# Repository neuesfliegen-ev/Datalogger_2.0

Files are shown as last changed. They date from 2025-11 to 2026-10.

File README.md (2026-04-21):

# 🛩️ Datalogger_2.0 

Datalogger for collecting, logging and transmitting RC flight data during the New Flying Competition
organised and held by the Neues Fliegen e.V.
Continuation of project Datalogger (first version)

---

## 🧩 Improvements

- Remove SIM card and use radio communication for telemetry
- Improve IMU sensor stability on flight
- Develop more efficient calibration process
- Develop a ground station capable of receiving and uploading live telemetry
- Implement FreeRTOS on ESP32

---

## 📦 Features

- Logs data to SD card in `.csv` format
- Captures:
  - 9-axis IMU data (acceleration, gyroscope, magnetometer)
  - Barometric pressure, altitude, and temperature
  - GPS coordinates, altitude, speed, and satellite count
- Streams telemetry to ground station through radio communication
- Ground station streams telemetry to web server
//to be refined

## 🧠 Core Components

| Component 	| Description |
|---|---|
| **ESP32** 		| Primary microcontroller |
| **WT-901B** 			  | 10-DOF IMU (acceleration, gyroscope, magnetometer + barometer)  |
| **GEP M10** 	| GEP-M10 GPS module utilizing the u-blox M10050 GPS chip |
| **Digital pitot sensor** | PixHawk PX4 digital airspeed sensor |
| **E22-900T30D LoRa module**	| Enables the transmission of live telemetry via radio communication to ground station|
| **SD Card Module** 	| Stores `.csv` data logs |
//more to be added

---

## 🔧 Circuit Diagram
//to be added

---

## 👨‍💻 Credits

- Developed by the **Neues Fliegen e.V.** team
- Based on libraries by Arduino...

---

## 📷 License

- This project is shared publicly for educational and personal use only.
Commercial use or sale is not permitted without explicit permission
from Neues Fliegen e.V.
- see LICENSE file

---

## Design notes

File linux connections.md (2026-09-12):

# LoRa Radio Module Configuration & Message Transmission

## Radio Module Configuration
Problem with radio link? It's usually the hardware settings (module configuration).

Configuration settings to be set:
| AT command | Meaning |
|---|---|
| AT+UART=7,0 | 115200 baud rate, 8N1 |
| AT+RATE=5 | 19.2 kbps |
| AT+CHANNEL=1 | using channel 1 |
| AT+ADDR=1 | set different number for each module |

### 1. Wiring

Wire the USB-TTL converter to the LoRa module.

| Pin | Level |
|---|---|
| M1 | HIGH |
| M0 | GND |

### 2. Configure the Serial Port

In the **left terminal window**, connect to the correct `/dev/ttyUSB0` port:

```bash
sudo stty -F /dev/ttyUSB0 115200 cs8 -cstopb -parenb raw -echo
```

If the module hasn't been set to 115200 baud rate yet, then use the default 9600.

!!!!!You need the raw or else u get an error

### 3. Listen to the Port

In the **left terminal window**:

```bash
cat /dev/ttyUSB0
```

Keep this running to listen for responses from the module.

### 4. Send an AT Command

In the **right terminal window**:

```bash
sudo echo "AT+HELP=?" > /dev/ttyUSB0
```

### Common Errors

#### Port Busy

Usually caused by another program or terminal session already using `/dev/ttyUSB0`.

Close the other session or application using the port.

#### Permission Denied

If you get a permission error when accessing the serial port, add your user to the `dialout` group:

```bash
sudo usermod -aG dialout $USER
```

Log out and back in for the group change to take effect.

---

# Sending Messages

For normal transmission mode, set both pins to GND:

| Pin | Level |
|---|---|
| M1 | GND |
| M0 | GND |

### 1. Keep the Listener Running

Keep the following command running in the **left terminal window**:

```bash
cat /dev/ttyUSB0
```

### 2. Send Binary Data

In the **right terminal window**:

```bash
printf '\x01\x02\x03\x04' > /dev/ttyUSB0
```

### 3. Send Text

Send plain text:

```bash
printf 'text' > /dev/ttyUSB0
```

Or send text followed by a newline:

```bash
printf 'text\n' > /dev/ttyUSB0
```

The receiving LoRa module should output the transmitted data through its serial interface.



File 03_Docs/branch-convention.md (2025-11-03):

# 🌳 Branch Naming & Workflow Convention

To keep our collaboration organized and avoid conflicts, please follow these guidelines when creating and managing branches.

> See also: [📜 GitHub Best Practices](\docs\github-best-practices.md)

---

### 🌿 1. Creating Branches
- **Create a new branch** for every new feature, bug fix, or major change.  
- Ideally, **one person works on one branch** at a time.  
  This keeps history clean and prevents conflicting edits.

---

### 🏷️ 2. Naming Conventions
- Use **descriptive, lowercase, hyphen-separated names** that reflect the purpose of the branch.  
  Examples:
  - `feature/implement-oled`
  - `bugfix/fix-timing-loop`
  - `experiment/new-gps-module`

This makes it easy for everyone to understand what each branch is for at a glance.

---

### 🔄 3. Keeping Your Branch Up to Date
- If `main` gets updated while you’re working, **rebase your branch** onto the latest `main`.  
  This ensures your work includes the newest changes and reduces merge conflicts later.  
  *(Command line: `git fetch origin && git rebase origin/main` or let GitHub Desktop handle it 🤷🏼)*.

---

### 🚀 4. Opening Pull Requests
- When your code is ready and tested, **push your branch** to GitHub and open a **Pull Request (PR)**.  
- Request at least one teammate to review before merging into `main`.

---

### 🧹 5. Cleaning Up
- After your PR is merged, delete your branch locally. Your branch on GitHub will be deleted automatically.
- This keeps the repository tidy and prevents confusion.

---

### 🤓☝🏼 6. Exceptions
- If you’re working on something that **no one else will touch** (e.g., a personal test file or documentation),  
  you don’t need to strictly follow this branching convention.  
- Just make sure your work doesn’t interfere with shared code.

---

### ⚠️ Important Notes

- Never rebase or force-push shared branches that others might be using.
Only rebase your own feature branches.

- When in doubt, **ask before merging** — better a small delay than broken code!

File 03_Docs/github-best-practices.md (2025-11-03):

# 📜 GitHub Best Practices

A few simple habits to keep our workflow smooth, organized, and conflict-free.

> See also: [🌿 Branch Naming & Workflow Convention](\docs\branch-convention.md)

---

### 💬 1. Commit Messages
- Keep commit messages **short, clear, and descriptive**.  
  *(Example: “Fix timing issue in motor control loop”)*  
- Write messages that explain **what** changed and, if relevant, **why**.

---

### 💾 2. Committing
- **Commit often** — after completing a small, logical unit of work.  
- It’s okay to commit code that’s incomplete or not yet working, as long as it’s **not pushed**.  
  Think of commits as personal save points.

---

### 🔄 3. Staying Updated
- **Fetch (or pull) from `main` regularly** to stay in sync with the latest changes.  
  This reduces merge conflicts and keeps your branch current.
  
---
  
### 🚀 4. Pushing
- **Push only when your code builds and runs reliably.**  
  That way, the shared repository always reflects working code.  
- After rebasing or resolving conflicts, remember to push with  
  `--force-with-lease` (or let GitHub Desktop handle it 🤷🏼).

---

### 🌿 5. Branching
- **Create a new branch for every feature, fix, or experiment.**  
  *(Example: `feature/add-sensor`, `bugfix/fix-display`)*  
- Keep branches short-lived — merge them once the feature is complete and tested.

---

### 📝 Summary
- Commit early, push late.  
- Fetch often, branch freely, and ***keep `main` clean***. (please)

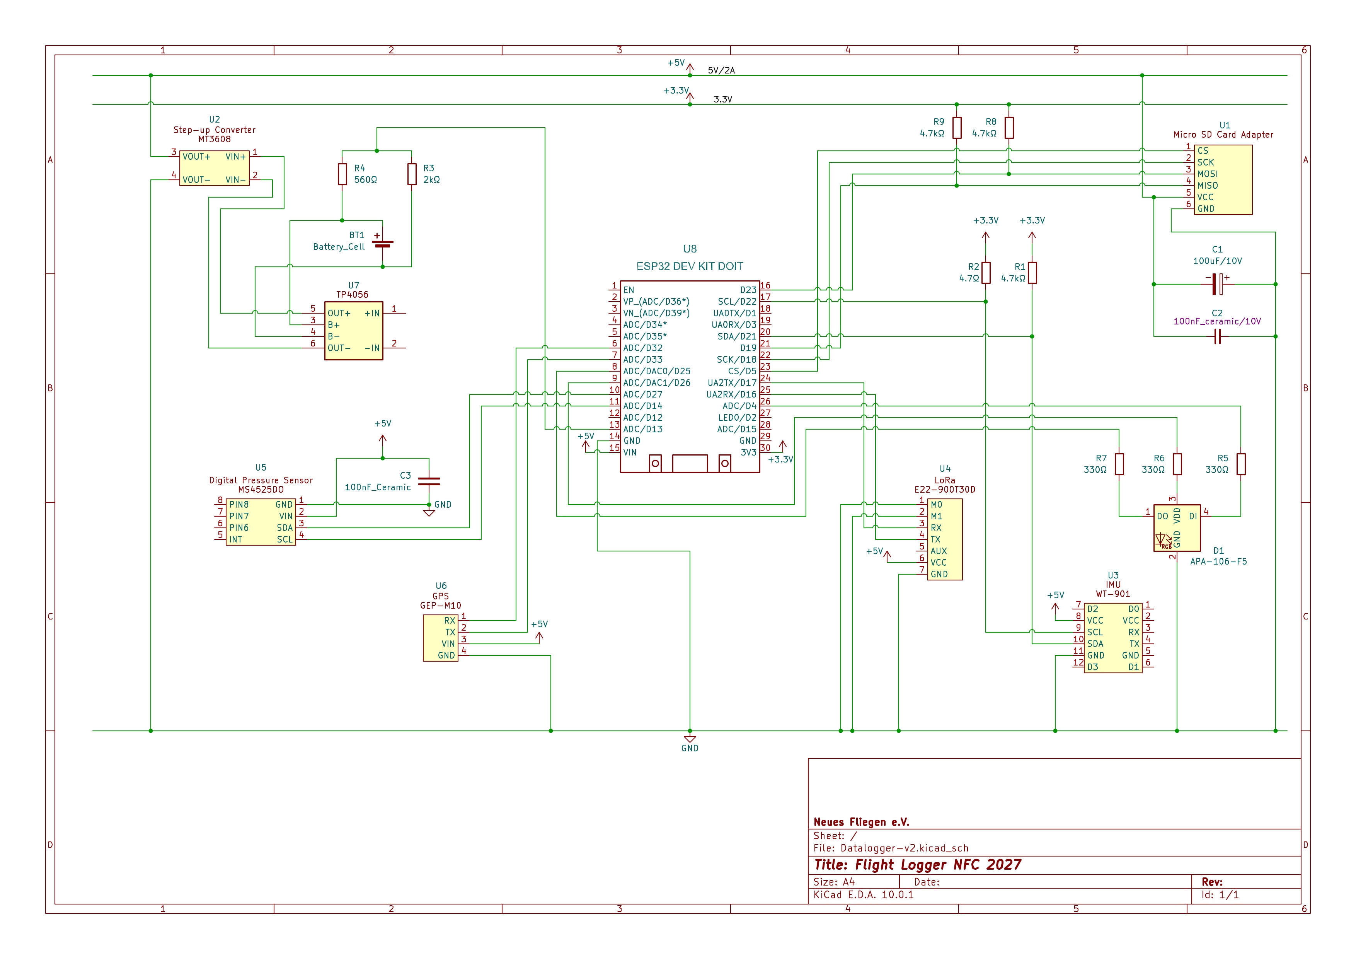
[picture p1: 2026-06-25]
02_PCB/Schematic Flight Logger NFC27 v1.0.jpg

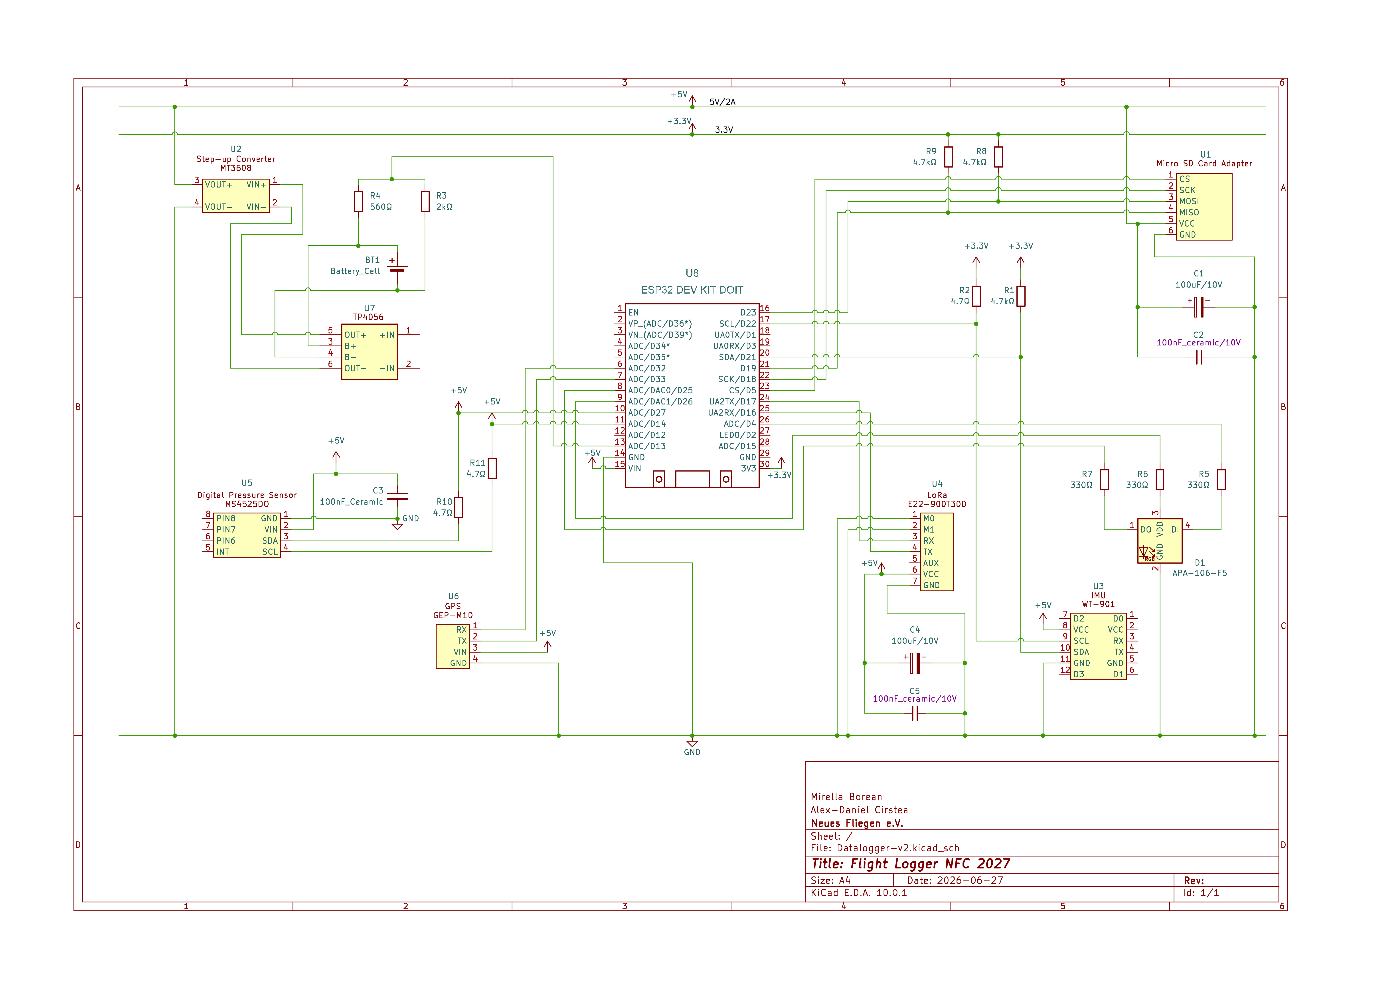
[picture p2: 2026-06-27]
02_PCB/Schematic Flight Logger NFC27 27-06 v1.1.png

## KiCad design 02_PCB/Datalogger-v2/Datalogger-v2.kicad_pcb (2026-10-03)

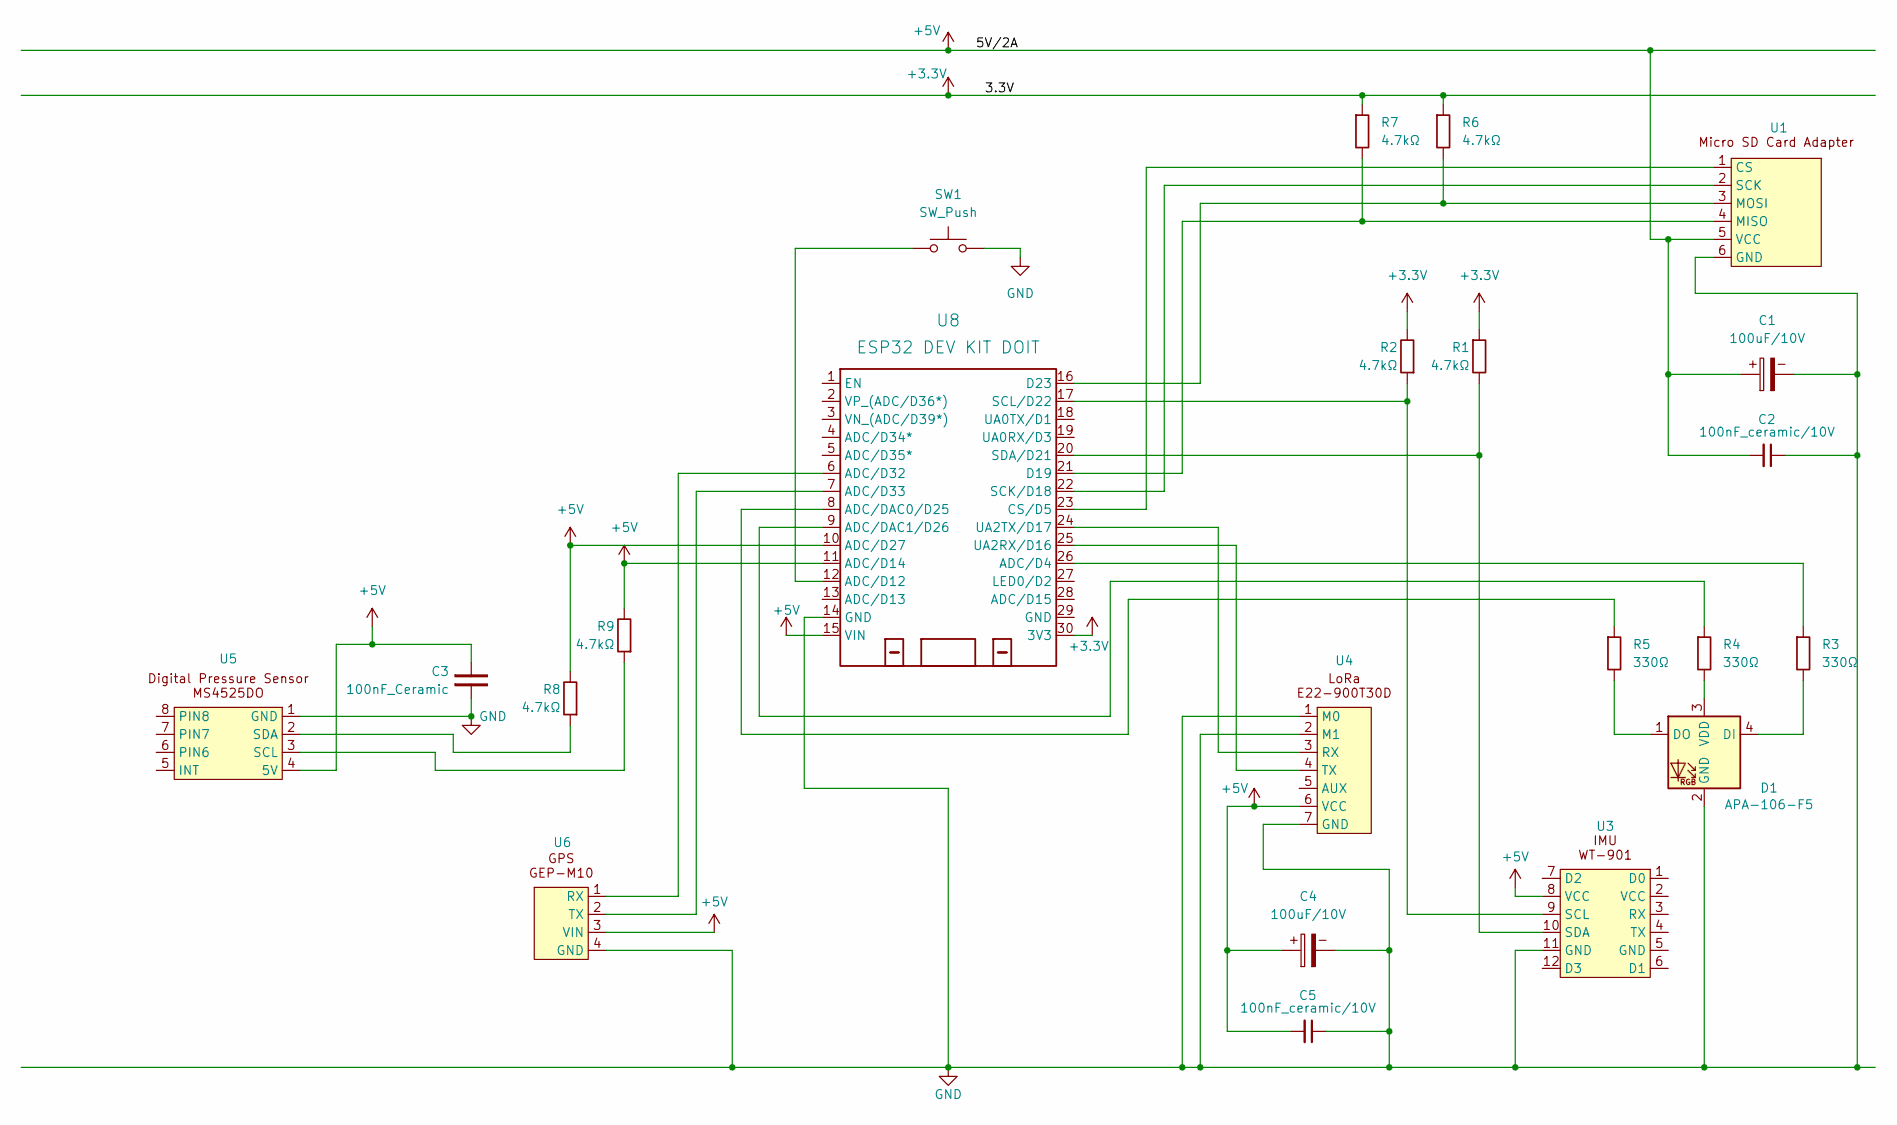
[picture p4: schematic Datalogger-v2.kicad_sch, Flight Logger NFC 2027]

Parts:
C1, C4: 100uF/10V; CP_Radial_D5.0mm_P2.50mm
C2, C5: 0.1uF_0603_16V; C_0805_2012Metric_Pad1.18x1.45mm_HandSolder; Part Number 0603YC104KAT2A; JLCPCB ID C14663
C3: 100nF_Ceramic; C_0805_2012Metric_Pad1.18x1.45mm_HandSolder
D1: APA-106-F5; LED_D5.0mm-4_RGB
R1, R2, R6, R7, R8, R9: 4.7kΩ; R_Axial_DIN0207_L6.3mm_D2.5mm_P10.16mm_Horizontal
R3, R4, R5: 330Ω; R_Axial_DIN0207_L6.3mm_D2.5mm_P10.16mm_Horizontal
SW1: SW_Push; SW_PUSH_6mm
U1: Micro SD Card Adapter; Micro_SD_Adapter
U3: WT901B
U4: E22-900T30D
U5: MS4525DO
U6: GPS GEP-M10
U8: ESP32 DEV KIT DOIT; DOIT-ESP32-DEVKIT-V1

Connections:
+3.3V: R1.1, R2.2, R6.1, R7.1, U8.30 (3V3)
+5V: C1.1, C2.2, C3.1, C4.1, C5.2, R8.2, R9.2, U1.5 (VCC), U3.8 (VCC), U4.6 (VCC), U5.4 (5V), U6.3 (VIN), U8.10 (ADC/D27), U8.11 (ADC/D14), U8.15 (VIN)
GND: C1.2, C2.1, C3.2, C4.2, C5.1, D1.2 (GND), SW1.2, U1.6 (GND), U3.11 (GND), U4.1 (M0), U4.2 (M1), U4.7 (GND), U5.1 (GND), U6.4 (GND), U8.14 (GND)
unnamed: D1.4 (DI), R3.2
unnamed: D1.1 (DO), R5.2
unnamed: D1.3 (VDD), R4.2
unnamed: U1.1 (CS), U8.23 (CS/D5)
unnamed: R7.2, U1.4 (MISO), U8.21 (D19)
unnamed: R6.2, U1.3 (MOSI), U8.16 (D23)
unnamed: U1.2 (SCK), U8.22 (SCK/D18)
unnamed: R2.1, U3.9 (SCL), U8.17 (SCL/D22)
unnamed: R1.2, U3.10 (SDA), U8.20 (SDA/D21)
unnamed: U4.3 (RX), U8.24 (UA2TX/D17)
unnamed: U4.4 (TX), U8.25 (UA2RX/D16)
unnamed: R9.1, U5.3 (SCL)
unnamed: R8.1, U5.2 (SDA)
unnamed: U6.1 (RX), U8.6 (ADC/D32)
unnamed: U6.2 (TX), U8.7 (ADC/D33)
unnamed: R3.1, U8.26 (ADC/D4)
unnamed: SW1.1, U8.12 (ADC/D12)
unnamed: R5.1, U8.8 (ADC/DAC0/D25)
unnamed: R4.1, U8.9 (ADC/DAC1/D26)

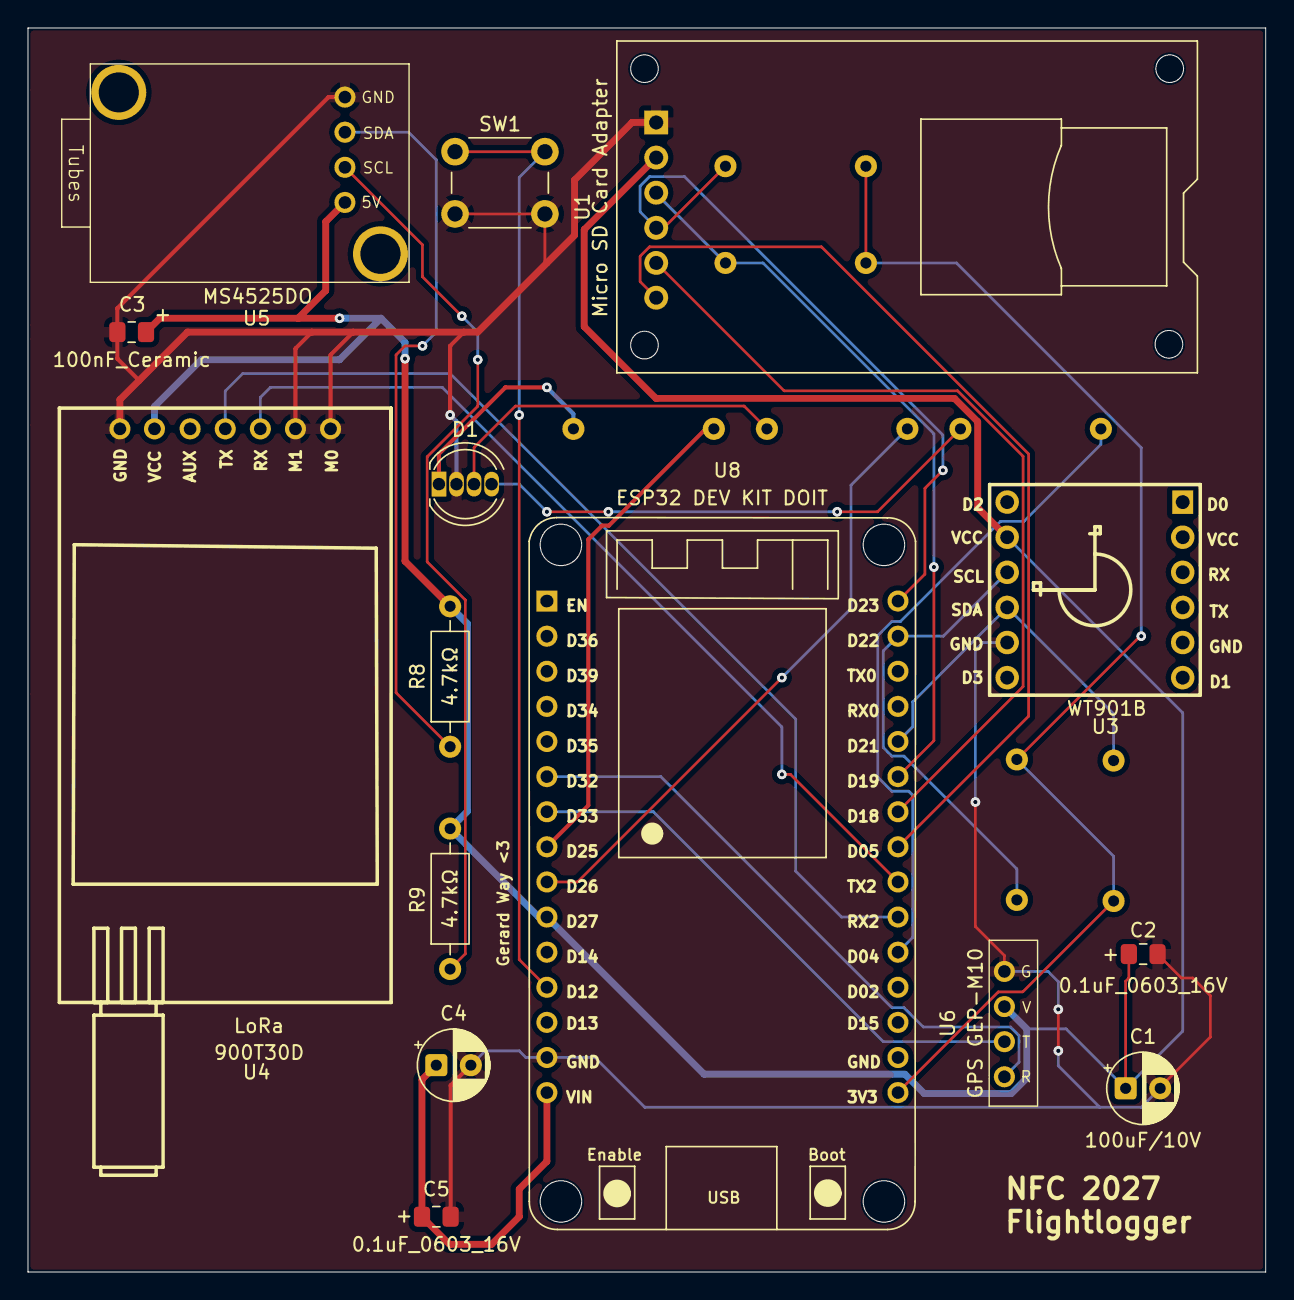
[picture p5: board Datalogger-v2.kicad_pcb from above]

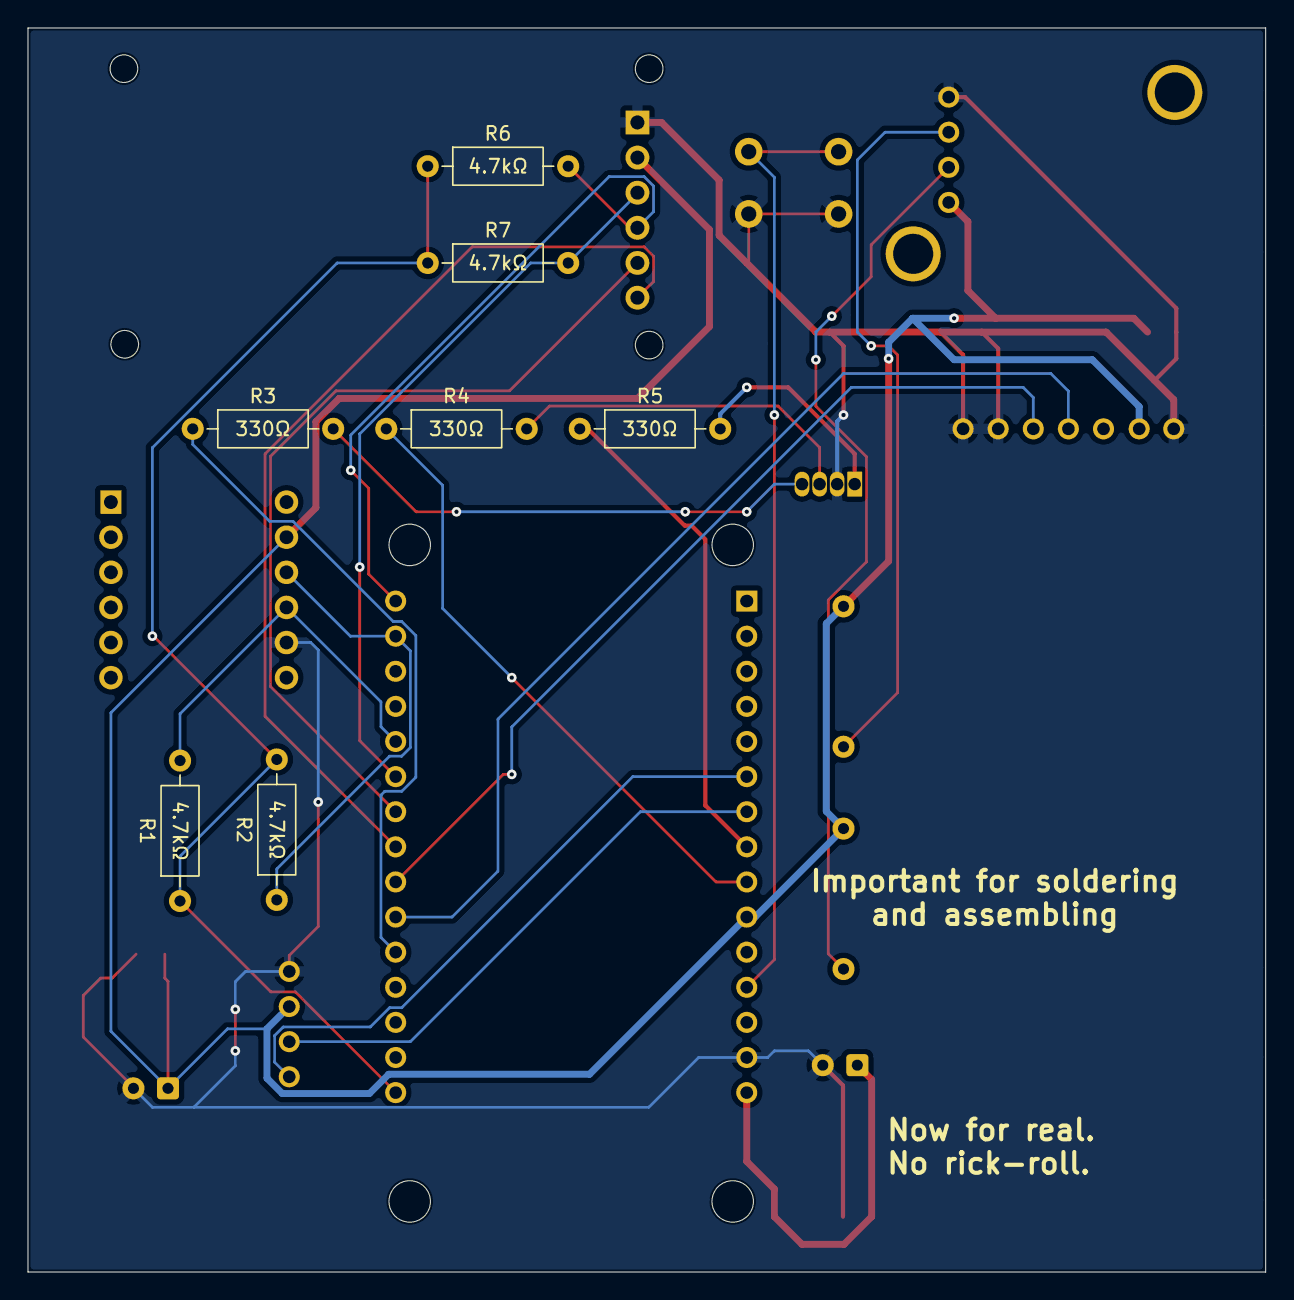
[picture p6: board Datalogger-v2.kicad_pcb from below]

Board: 2 copper layers, 89.5 x 90.0 mm, 22 parts (7 on the bottom side), 22 nets.

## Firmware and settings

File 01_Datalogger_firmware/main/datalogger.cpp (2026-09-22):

/*DO NOT RUN BUS SETUP FUNCTIONS WITHOUT HARDWARE CONNECTION: comment out in serial_buses_setup()*/

/* C Libraries */
#include <stdio.h>
#include <string.h>

/* ESP-IDF */
#include "freertos/FreeRTOS.h"
#include "freertos/task.h"
#include "esp_timer.h"
#include "esp_log.h"
#include "driver/gpio.h"
#include "driver/i2c_master.h"
#include "driver/uart.h"
#include "driver/spi_common.h"
#include "driver/sdspi_host.h"
#include "sdmmc_cmd.h"

/* Local */
#include "pins.h"
#include "setup.h"
#include "hal/radio.h"
#include "hal/imu.h"
#include "hal/gps.h"
#include "hal/airspeed.h"
#include "modules/telemetry.h"
#include "modules/commandHandler.h"
#include "hal/sd_card.h"

/* Settings */
bool DEBUG = true;
bool TELEMETRY_ENABLED = false;
bool LOGGING_ENABLED = true;

QueueHandle_t datasetQueue;
QueueHandle_t radioQueue;
int command, option; 

//Module objects
SDCard sd;
Telemetry telemetry;
CJY901 IMU;
AirspeedClass airspeed;
GPSClass GPS;
RadioClass Radio(RADIO_M0_PIN, RADIO_M1_PIN);
CommandHandler commandHandler(Radio, IMU, airspeed, GPS, sd, telemetry, LOGGING_ENABLED, TELEMETRY_ENABLED);

static uint32_t last_gps_update = 0;
static uint32_t last_imu_update = 0;
static uint32_t last_airspeed_update = 0;
static uint32_t last_radio_tx = 0;

void generateFileName(char *buffer, size_t buffer_size){
    int64_t ms = esp_timer_get_time() / 1000;

    snprintf(
        buffer,
        buffer_size,
        "/sdcard/21062026_%lld_test_file.bin",
        ms
    );
}

void update_all_sensor_data(){
	uint32_t now = esp_timer_get_time() / 1000;
	/* **update all the data structs**/
	/*0.7 ms*/
	if (now - last_airspeed_update >= AIRSPEED_UPDATE_PERIOD) {
	int64_t t0 = esp_timer_get_time();
	esp_err_t err = airspeed.read();
		//int64_t t1 = esp_timer_get_time();
		//printf("airspeed read time = %.2f ms\n", (t1 - t0) / 1000.0);    	
	last_airspeed_update = now;
	}	

	/*$=ms max.*/
	if (now - last_gps_update >= GPS_UPDATE_PERIOD) {
		int64_t t2 = esp_timer_get_time();	
    	GPS.update();
    	int64_t t3 = esp_timer_get_time();
    	//printf("gps read time = %.2f ms\n", (t3 - t2) / 1000.0);    	
    	last_gps_update = now;
	}	
	/*6ms?*/
	int64_t t4 = esp_timer_get_time();
	IMU.updateAll(); 
		int64_t t5 = esp_timer_get_time();
    	//printf("IMU read time = %.2f ms\n", (t5 - t4) / 1000.0);    		
	last_imu_update = now;
	/*1ms?*/
	telemetry.update_telemetry(now, IMU, GPS, airspeed); 

	if(DEBUG) ESP_LOGI("TELEMETRY", "updated telemetry\n");
}

//Read sensors, read radio commands
void polling_task(void *pvParameters) {
	RadioMessage msg;
    
    for(;;) {
    	
    	update_all_sensor_data(); 

        // Queue data for SD
        if (LOGGING_ENABLED) {
            if (xQueueSend(datasetQueue, &telemetry.dataset, 0) != pdTRUE) {
                ESP_LOGW("SD QUEUE", "datasetQueue full, sample dropped");
            }
        }    
		
		if (Radio.readCommand(command, option)){
			commandHandler.executeCommand(command, option);
		}

		uint32_t now = esp_timer_get_time() / 1000;
		if(TELEMETRY_ENABLED && (now - last_radio_tx > TELEMETRY_PERIOD)){
			int64_t t0 = esp_timer_get_time();
			Radio.sendDataset(&telemetry);
			int64_t t1 = esp_timer_get_time();

			printf("sendDataset took %.2f ms\n", (t1 - t0) / 1000.0);
			last_radio_tx = now;
		}

        // IMPORTANT: give other tasks CPU time
        vTaskDelay(pdMS_TO_TICKS(10));

    }
}

//Radio TX Parsing
void radio_tx_task(void *arg) {
    RadioMessage msg;

    for (;;) {
    	if(TELEMETRY_ENABLED){
    		// Blocking is fine here because this task ONLY handles TX
    		if (xQueueReceive(radioQueue, &msg, portMAX_DELAY) == pdTRUE) {

            int written = uart_write_bytes(RADIO_UART_NUM, msg.text, msg.len);

            if(DEBUG)ESP_LOGI("RADIO TX","sent %d/%d bytes",written,msg.len);
        	}
    	}
    }
}

//Log to SD
void logging_task(void* arg) {
	if(LOGGING_ENABLED){
		SDataset writeBuffer[32];
		size_t count = 0;
		uint32_t flush_counter = 0;

		for (;;) {
		    SDataset sample;
		    
		    if (xQueueReceive(datasetQueue, &sample, portMAX_DELAY) == pdTRUE) {
		        writeBuffer[count++] = sample;
		        if (count >= 32) {
		            esp_err_t err = sd.writeDatasets(writeBuffer, count);
		            if (err != ESP_OK) {
	    				ESP_LOGE("SD", "write failed: %s", esp_err_to_name(err));
					}else{
						ESP_LOGW("SD QUEUE", "wrote to sd card");					
					}
		            count = 0;

		            flush_counter++;

		            if (flush_counter >= 4) {
		                esp_err_t errFlush = sd.flush();
		                if(errFlush != ESP_OK) ESP_LOGE("SD QUEUE", "flush failed");
						
						if (err != ESP_OK) {
						    ESP_LOGE("SD QUEUE", "SD end failed: %s", esp_err_to_name(err));
						}	                
						flush_counter = 0;
						int time = esp_timer_get_time();
						if(time >= 300000000) sd.end();
		            
		            }
		            if(DEBUG) ESP_LOGI("SD CARD", "flushed file");	        
		        }
		    }
		}		
	}

}

extern "C" void app_main(){
	//esp_bt_controller_mem_release(ESP_BT_MODE_BTDM);
	sd.begin();
	serial_buses_setup();

	/*Create binary file (test phase) ---------
	char filename[64];
	generateFileName(filename, sizeof(filename));
	sd.openLogFile(filename);
	-----------------------------------------*/

	radioQueue = xQueueCreate(10, sizeof(RadioMessage));
	Radio.setQueue(radioQueue);

	datasetQueue = xQueueCreate(32, sizeof(SDataset));

	   // Sensors + command RX
    xTaskCreatePinnedToCore(
        polling_task,
        "polling_task",
        4096,
        NULL,
        5,
        NULL,
        0
    );

    // Radio TX
    xTaskCreatePinnedToCore(
        radio_tx_task,
        "radio_tx_task",
        2048,
        NULL,
        4,
        NULL,
        0
    );

	xTaskCreatePinnedToCore(logging_task, "logging_task", 6144, NULL, 6, NULL, 1);
	//xTaskCreatePinnedToCore(gps_task, "gps_task", 1024, NULL, 7, NULL, 0);

	//Verify radio link by sending message over UART
	Radio.sendMessage("hello hello hello, datalogger radio link is up\n");

}

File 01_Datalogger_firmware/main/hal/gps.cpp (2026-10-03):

#include <cstring>
#include <cstdlib>
#include "freertos/FreeRTOS.h"

#include "driver/uart.h"
#include "hal/gps.h"


void GPSClass::startUART(uart_port_t p){
	uart_num = p;
}

void GPSClass::update(){
    uint8_t c;

    while (uart_read_bytes(uart_num, &c, 1, 5 / portTICK_PERIOD_MS) > 0) {
        if (c == '\n') {
            line_[index_] = '\0';

            if (index_ > 6 && line_[0] == '$') {
                parseLine(line_);
            }

            index_ = 0;
        } else if (c != '\r') {
            if (index_ < sizeof(line_) - 1) {
                line_[index_++] = static_cast<char>(c);
            } else {
                index_ = 0;
            }
        }
    }
}

void GPSClass::parseLine(char* line) {
    if (std::strstr(line, "GGA")) {
        parseGGA(line);
    } else if (std::strstr(line, "RMC")) {
        parseRMC(line);
    } else if (std::strstr(line, "VTG")) {
        parseVTG(line);
    }
}

void GPSClass::parseGGA(char* line)
{
    char* f[16] = {};
    splitNMEA(line, f, 16);

    parseTime(f[1], dateTime_.time);

    if (f[2] && f[3])
        gps_.latitude = parseCoord(f[2], f[3][0]);

    if (f[4] && f[5])
        gps_.longitude = parseCoord(f[4], f[5][0]);

    if (f[7])
        gps_.satellites = static_cast<uint8_t>(std::atoi(f[7]));

    if (f[9])
        gps_.altitude = parseAltitude(f[9]);
}

void GPSClass::parseRMC(char* line)
{
    char* f[16] = {};
    splitNMEA(line, f, 16);

    if (!f[2] || f[2][0] != 'A') return;

    parseTime(f[1], dateTime_.time);

    if (f[3] && f[4])
        gps_.latitude = parseCoord(f[3], f[4][0]);

    if (f[5] && f[6])
        gps_.longitude = parseCoord(f[5], f[6][0]);

    if (f[7])
        gps_.speed = parseSpeedKnots(f[7]);

    if (f[9])
        parseDate(f[9], dateTime_.date);
}

void GPSClass::parseVTG(char* line)
{
    char* f[16] = {};
    splitNMEA(line, f, 16);

    if (f[7])
        gps_.speed = static_cast<uint16_t>(std::atof(f[7]) * 100.0);
}

int GPSClass::splitNMEA(char* line, char* fields[], int maxFields)
{
    int count = 0;

    char* star = std::strchr(line, '*');
    if (star) *star = '\0';

    char* p = line;

    while (p && count < maxFields) {
        fields[count++] = p;

        p = std::strchr(p, ',');
        if (p) {
            *p = '\0';
            p++;
        }
    }

    return count;
}

int32_t GPSClass::parseCoord(const char* s, char hemi)
{
    if (!s || !*s) return 0;

    double raw = std::atof(s);
    int deg = static_cast<int>(raw / 100);
    double min = raw - deg * 100;
    double dec = deg + min / 60.0;

    if (hemi == 'S' || hemi == 'W') dec = -dec;

    return static_cast<int32_t>(dec * 10000000.0);
}

int32_t GPSClass::parseAltitude(const char* s)
{
    if (!s || !*s) return 0;
    return static_cast<int32_t>(std::atof(s) * 100.0);
}

uint16_t GPSClass::parseSpeedKnots(const char* s)
{
    if (!s || !*s) return 0;

    double knots = std::atof(s);
    double kmh = knots * 1.852;

    return static_cast<uint16_t>(kmh * 100.0);
}

void GPSClass::parseTime(const char* s, SGPSTime& time)
{
    if (!s || !*s) return;

    double val = std::atof(s);
    uint32_t whole = static_cast<uint32_t>(val);

    time.hour = whole / 10000;
    time.minute = (whole / 100) % 100;
    time.second = whole % 100;
    time.millisecond = static_cast<uint16_t>((val - whole) * 1000.0);
}

void GPSClass::parseDate(const char* s, SGPSDate& date)
{
    if (!s || !*s) return;

    uint32_t val = static_cast<uint32_t>(std::atoi(s));

    date.day = val / 10000;
    date.month = (val / 100) % 100;
    date.year = 2000 + (val % 100);
}

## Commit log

2025-10-29 Create aboutthisfolder.txt
    for arduino testing
2026-02-27 Manuals
    - IMU: WT901
    - Microcontroller: ESP32
    - Radio Module: E22-900T30D
2026-02-27 Manuals
    LiPo battery
2026-03-27 Implement Pitot sensor module
    - Implement Pitot class in Pitot.cpp and Pitot.h.
    - Add functions for differential pressure and airspeed calculation.
    - Initialize and handle raw I2C sensor readings with EMA filtering.
2026-04-20 Removed Arduino directory
    Unneeded
2026-04-20 Create README.md
    Everything for ground station
2026-04-21 working imu driver
2026-04-30 imu folder
2026-05-04 added com ports and bug fixes
    [radio.cpp]
2026-05-15 Create PCB folder
2026-05-15 Create PCB directory
2026-05-15 Add schematic and PCB files
    [Datalogger-v2.kicad_pcb, Datalogger-v2.kicad_sch]
2026-05-20 change files names to imu.h
2026-05-20 Change folder name and structures
    [Datalogger-v2.kicad_pcb, Datalogger-v2.kicad_sch]
2026-06-03 separated imu register file to prevent conflicts with global; bug fixes in gps and imu classes
    [datalogger.cpp, gps.cpp]
2026-06-09 added airspeed sensor classes and updated Telemetry
2026-06-10 Update PCB schematic
    [Datalogger-v2.kicad_pcb, Datalogger-v2.kicad_sch]
2026-06-10 Update schematic and PCB files
    - Add symbol and footprint library.
    [Datalogger-v2.kicad_pcb, Datalogger-v2.kicad_sch]
2026-06-10 Update PCB file
    - Fix design rules
    - Add tracks
    [Datalogger-v2.kicad_pcb, Datalogger-v2.kicad_sch]
2026-06-14 Update PCB file
    [Datalogger-v2.kicad_pcb]
2026-06-15 Update schematic and PCB files
    [Datalogger-v2.kicad_pcb, Datalogger-v2.kicad_sch]
2026-06-23 Update schematic
    [Datalogger-v2.kicad_pcb, Datalogger-v2.kicad_sch]
2026-06-23 Update schematic and PCB layout
    [Datalogger-v2.kicad_pcb, Datalogger-v2.kicad_sch]
2026-06-25 Upload schematic screenshot
    [Datalogger-v2.kicad_pcb]
2026-07-02 Update PCB layout
    [Datalogger-v2.kicad_pcb]
2026-07-24 Update schematics and PCB design
    [Datalogger-v2.kicad_pcb, Datalogger-v2.kicad_sch]
2026-08-03 Update schematics and PCB layout
    [Datalogger-v2.kicad_pcb]
2026-08-30 added calibration+logging commands; test with radio link
2026-09-08 quick edit
    Added instructions for wiring and configuration of the LoRa module.
2026-09-08 Revise LoRa Radio Module configuration documentation
    Updated the documentation for LoRa Radio Module configuration, including wiring, serial port configuration, and message transmission instructions.
2026-09-12 radio link working, commands work as long as radio module configuration is correct (air rate, baud rate, channel number, different addresses. check github)
    [commandHandler.cpp, datalogger.cpp, radio.cpp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]
2026-10-03 added calibration commands for each sensor, incl. gps sat count check
2026-10-03 Update PCB layout and schematic
    - Removed Step-Up Converter and Battery Charger
    - Added button
    - Fixed errors
    [Datalogger-v2.kicad_pcb, Datalogger-v2.kicad_sch]
2026-10-12 Update PCB layout
    - Change SD Card Reader layer
    - Add holes for soft mount
2026-10-26 Update footprints and library
    - Added missing footprint library files
    - Changed footprints
2026-10-26 Update PCB layout and footprints library
    - Sync schematic and PCB
    - Fixed more errors in footprints library
    - Updated PCB layout
2026-10-29 Update PCB
